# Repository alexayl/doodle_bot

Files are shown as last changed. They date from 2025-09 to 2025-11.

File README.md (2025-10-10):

# Doodle Bot

DoodleBot device for autonomous whiteboard management.

This repository is setup as a **monorepo** that contains the code for the different subsystems that are flashed to different devices. Please see the links below for each subsystems' README:

- [Firmware](firmware/README.md) (Alex Aylward and Jain Iftesam) is responsible for all of the code on the device.
- [CV Software](cv_software/README.md) (Trevor Antle is responsible for developing the Computer Vision application
- [Pathfinding](pathfinding/README.md) (Tom Concannon) is responsible for the path generation algorithm

## Setup

### Docs

Requirements: graphviz

### Firmware

_Note: If you are on a PC, Zephyr does not work well with WSL. Please use Windows native, or consider eventually dual-booting/VM linux!_

1. Install prerequisites

    - [Python3](https://www.geeksforgeeks.org/python/download-and-install-python-3-latest-version/)

    - Complete **only** the [Install Dependencies](https://docs.zephyrproject.org/latest/develop/getting_started/index.html#install-dependencies) section of the [Getting Started Guide](https://docs.zephyrproject.org/latest/develop/getting_started/index.html#getting-started-guide).

    - [Just command runner](https://github.com/casey/just?tab=readme-ov-file#installation) - This is used like a makefile as a hotkey for all of our project-specific commands
        - If you are using Windows, installing chocolatey package manager is recommended. After installing chocolatey, you can install just by running `choco install just`.
        - If you are on Mac, use the [Homebrew](https://brew.sh/) command `brew install just`.

If building/flsahing for [nrf52840 dk](https://docs.zephyrproject.org/latest/boards/nordic/nrf52840dk/doc/index.html):
    - SEGGER J-Link DLL
    - nrfutil (there is a python lib that allegedly has it; I needed to install it from the website though due to python dependency version conflicts)
    - 
2. Clone this repository:
    ```bash
    git clone git@github.com:alexayl/doodle_bot.git
    cd doodle_bot
    ```

3. Create and activate a Python virtual environment:
    ```bash
    python -m venv .venv
    
    source .venv/bin/activate     # Linux/macOS
    .venv\Scripts\activate.bat    # PC, Command Prompt
    .venv\Scripts\Activate.ps1    # PC, Powershell
    source .venv/Scripts/activate # PC. Git bash
    ```

4. Install west
    ```bash
    pip install west
    ```

5. Update the workspace
    ```bash
    cd firmware
    west update
    west packages pip --install
    ```

6. Install the Zephyr SDK
    1. navigate to `doodle_bot/firmware/zephyr`
        ```bash
        cd zephyr
        ```
    2.  Perform installation 
        ```bash
        west sdk install
        ```

7. Try to build and run
    1. navigate to `doodle_bot/firmware`
        ```bash
        cd ..
        ```
    2.  Build the sim to verify it works 
        ```bash
        just run-sim
        ```

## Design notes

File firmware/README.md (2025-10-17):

# Doodlebot Firmware
 
## Overview

The firmware contains two main parts. Please see the READMEs for each individual part for more information.

- [Application](app/README.md) (Alex Aylward) - The high-level logic
- [Drivers](drivers/README.md) (Jain Iftesam) - Hardware drivers and peripheral interfaces

## Features

- Bluetooth Low Energy (BLE) Nordic UART Service (NUS) support
- Real-time sensor data collection and processing
- Motor control and movement coordination
- Wireless communication with computer vision system
- Hardware abstraction layer for multiple board targets

## Installation

### Setup to work on firmware

Note: If you are on a Windows PC, use WSL2 (look up install instructions, ubuntu recommended) and follow the instructions for linux

1. Install prerequisites

    - Python3

    - Complete **only** the [Install Dependencies](https://docs.zephyrproject.org/latest/develop/getting_started/index.html#install-dependencies) section of the [Getting Started Guide](https://docs.zephyrproject.org/latest/develop/getting_started/index.html#getting-started-guide).

    - [Just command runner](https://github.com/casey/just?tab=readme-ov-file#installation) - This is used like a makefile as a hotkey for all of our project-specific commands
        - If you are using Windows, installing chocolatey package manager is recommended. After installing chocolatey, you can install just by running `choco install just`.
        - If you are on Mac, use the [Homebrew](https://brew.sh/) command `brew install just`.

    - **Windows + WSL2**: usbipd-win - This is used to expose the USB ports to WSL2 so that flashing works properly

2. Clone this repository:
    ```bash
    git clone git@github.com:alexayl/doodle_bot.git
    cd doodle_bot
    ```

3. Create and activate a Python virtual environment:
    ```bash
    python -m venv .venv
    
    source .venv/bin/activate     # Linux/macOS
    .venv\Scripts\activate.bat    # PC, Command Prompt
    .venv\Scripts\Activate.ps1    # PC, Powershell
    source .venv/Scripts/activate # PC. Git bash
    ```

4. Install west
    ```bash
    pip install west
    ```

5. Update the workspace
    ```bash
    cd firmware
    west update
    west packages pip --install
    ```

6. Install the Zephyr SDK
    1. navigate to `doodle_bot/firmware/zephyr`
        ```bash
        cd zephyr
        ```
    2. Perform installation 
        ```bash
        west sdk install
        ```

7. Try to build and run
    1. navigate to `doodle_bot/firmware`
        ```bash
        cd ..
        ```
    2. Build the sim to verify it works 
        ```bash
        just run-sim
        ```

## Usage

### Building and Flashing

For nRF52840 DK:
```bash
# Build for nrf52840dk
west build -b nrf52840dk/nrf52840 app

# Flash to board
west flash
```

For other targets, see individual application READMEs for board-specific instructions.

### Testing BLE Connectivity

1. Flash the peripheral_nus sample to your board
2. Use nRF Connect mobile app to scan and connect
3. Subscribe to NUS notifications to receive "Hello World!" messages
4. Send data to test bidirectional communication

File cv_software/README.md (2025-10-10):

# DoodleBot Computer Vision

## Overview
The Computer Vision (CV) subsystem provides real-time localization and feedback for the DoodleBot platform.  
It runs on a Raspberry Pi 5 and integrates camera-based perception, geometric calibration, and marker-based pose estimation using **OpenCV** and **ArUco** detection.  
The subsystem continuously tracks the robot’s position and orientation on the drawing board and communicates live correction data to the firmware over Bluetooth.  
A Flask-based web interface enables real-time monitoring through annotated video streams and provides REST APIs for control, status, and telemetry.

## Features
- **Multi-threaded Frame Capture:**  
  Captures frames asynchronously at up to 30 fps using a low-latency video backend with sharpness and exposure filtering.
- **Board Calibration and Homography Mapping:**  
  Uses four fixed ArUco markers to compute a perspective transform that aligns the camera’s image space to the board coordinate system.
- **Marker-Based Localization:**  
  Detects two robot-mounted fiducial markers to determine position and heading in millimeter-scale precision.
- **Dynamic Scaling:**  
  Automatically derives pixel-to-millimeter conversion from board geometry or marker baseline.
- **Web Visualization and Telemetry:**  
  Streams annotated video, calibration metrics, and robot pose data via Flask endpoints for live visualization and integration with other subsystems.

## Installation
1. Clone the repository:
   ```bash
   git clone https://github.com/alexayl/doodle_bot.git
   cd cv_software
   ```

2. Create a virtual environment and install dependencies:
   ```bash
   python3 -m venv venv
   source venv/bin/activate
   pip install -r requirements.txt
   ```

3. (Optional) To improve latency, enable MJPEG mode for UVC cameras on Linux:
   ```bash
   v4l2-ctl -d /dev/video0 --set-fmt-video=width=1280,height=720,pixelformat=MJPG
   ```

4. Launch the application:
   ```bash
   python3 -m app.server
   ```

## Usage
- Access the web interface at `http://<raspberrypi-ip>:5000`.
- Modes:
  - **/draw:** Upload an image for path rendering.
  - **/erase:** Command the robot to clear the workspace.
- API Endpoints:
  - `/api/moves` – enqueue motion commands.
  - `/api/pen` – toggle pen state (up/down).
  - `/api/stop` – halt motion.
  - `/stream` – retrieve the live annotated camera feed.
  - `/health` – report calibration and detection status.
- Logs and captured images are stored in the `uploads/` directory.

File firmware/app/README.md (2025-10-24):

# Doodlebot Firmware Application

## Overview

The main application firmware for the DoodleBot project. This firmware implements a multi-threaded architecture for controlling the robot's movement, communication, and state management. The application coordinates between Bluetooth communication, navigation control, and system state management through a message queue system.

## Architecture

The application uses a threaded architecture with three main threads:

- **Communications Thread** (`comms_thread`) - Handles Bluetooth Low Energy (BLE) communication via Nordic UART Service (NUS)
- **Navigation Thread** (`nav_thread`) - Processes movement instructions and controls servo motors
- **State Management Thread** (`state_thread`) - Manages overall system state and coordination

Communication between threads is handled through Zephyr message queues, specifically the `gcode_cmd_msgq` for navigation instructions.

## Features

- **Bluetooth Low Energy (BLE) Communication**
  - Nordic UART Service (NUS) implementation
  - Wireless command reception from computer vision system
  - Real-time data transmission

- **Multi-threaded Architecture** 
  - Concurrent processing of communication, navigation, and state management
  - Message queue-based inter-thread communication
  - Priority-based thread scheduling

- **Hardware Control**
  - PWM-based servo motor control
  - LED status indicators
  - Custom servo driver integration

- **Navigation System**
  - G-code instruction parsing and execution
  - Servo position control for drawing operations
  - Coordinated movement patterns

## Usage

### Building and Running

From the firmware directory, use the provided just commands:

```bash
# Build and run on nrf52840dk (complete workflow)
just run-nrf

# Individual steps:
just build-nrf     # Build the application
just flash-nrf     # Flash to board
just monitor-nrf   # Monitor serial output

# Build and run in QEMU simulator
just run-sim

# Build and run BLE sample
just run-ble
```

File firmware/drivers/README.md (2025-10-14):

# Doodlebot Firmware Drivers

## Overview

This directory contains custom Zephyr RTOS drivers for the Doodlebot drawing robot. The drivers provide a clean abstraction layer between high-level control algorithms and low-level hardware interfaces, enabling intuitive control of motors, actuators, and feedback devices.

## Architecture

The driver architecture follows a layered approach:

```
┌─────────────────────────────────────────┐
│          Application Layer              │
│     (Path Planning, Drawing Logic)      │
└─────────────────────────────────────────┘
                    │
┌─────────────────────────────────────────┐
│        Control Thread (50 Hz)          │
│    (Motor Control, State Management)    │
└─────────────────────────────────────────┘
                    │
┌─────────────────────────────────────────┐
│          Driver API Layer              │
│     (stepper.h, buzzer.h, servo.h)     │
└─────────────────────────────────────────┘
                    │
┌─────────────────────────────────────────┐
│        Hardware Abstraction            │
│     (GPIO, Timers, Device Tree)        │
└─────────────────────────────────────────┘
                    │
┌─────────────────────────────────────────┐
│          Physical Hardware             │
│  (A4988 Steppers, Servos, Buzzer)     │
└─────────────────────────────────────────┘
```

## Features

### Stepper Motor Driver
- **Input Interface**: Angular velocity in degrees/second
- **Hardware Support**: A4988/DRV8825 stepper driver modules
- **Microstepping**: 16x microstepping for smooth motion
- **Real-time Control**: Optimized for 50 Hz velocity updates
- **Dual Motor Support**: Independent left/right wheel control

### Servo Motor Driver  
- **Input Interface**: Angle in degrees (0-180°)
- **Hardware Support**: Standard PWM servo motors
- **Dual Servo Control**: Eraser and marker pen control
- **Smooth Movement**: PWM-based positioning

### LED Driver
- **Input Interface**: Simple on/off control
- **Hardware Support**: GPIO-controlled LEDs
- **Status Indication**: Visual feedback for system states
- **Multi-LED Support**: Independent control of multiple LEDs

### Buzzer Driver
- **Input Interface**: Simple on/off and beep patterns
- **Hardware Support**: GPIO-controlled piezo buzzer
- **Feedback**: Audio feedback for user interactions

## Driver Details

### Stepper Motor Driver (`stepper/`)

**Purpose**: Controls dual stepper motors for robot movement

**Key Specifications**:
- **Motor Type**: 1.8° stepper motors (200 steps/revolution)
- **Driver Modules**: A4988 or DRV8825 with 16x microstepping
- **Resolution**: 3200 microsteps per revolution
- **Conversion**: `f_step = velocity_deg_s × (3200/360) = velocity_deg_s × 8.89`

**API Functions**:
```c
int stepper_init(void);
int stepper_enable(enum stepper_motor motor);
int stepper_set_velocity(enum stepper_motor motor, float velocity_deg_s);
int stepper_stop(enum stepper_motor motor);
float stepper_get_velocity(enum stepper_motor motor);
```

**Device Tree Binding**: `dts/bindings/stepper/stepper-driver.yaml`
```yaml
stepper_left: stepper_left {
    compatible = "doodle,a4988-stepper";
    micro-step-res = <16>;
    step-gpios = <&gpio0 5 GPIO_ACTIVE_HIGH>;      /* ESP32: GPIO5, nRF52: P0.02 */
    dir-gpios = <&gpio0 6 GPIO_ACTIVE_HIGH>;       /* ESP32: GPIO6, nRF52: P0.03 */
    en-gpios = <&gpio0 7 GPIO_ACTIVE_LOW>;         /* ESP32: GPIO7, nRF52: P0.04 */
    label = "LEFT_STEPPER";
};
```

**Hardware Interface**:
- **STEP**: GPIO pulse train at calculated frequency
- **DIR**: GPIO level for rotation direction (HIGH = clockwise)
- **EN**: GPIO level for driver enable/disable (Active LOW)

**A4988/DRV8825 Driver Connections**:
```
ESP32-S3/nRF52840 → A4988/DRV8825 Driver
STEP pin          → STEP
DIR pin           → DIR
EN pin            → EN (Enable)
3.3V              → VDD (logic power)
3.3V              → RESET (tie high)
3.3V              → SLEEP (tie high)
3.3V              → MS1, MS2, MS3 (for 16x microstepping)
GND               → GND
                    VMOT ← 12V Motor Power Supply
                    1A, 1B, 2A, 2B → Stepper Motor Phases
```

**Real-time Operation**:
- Designed for 50 Hz velocity updates from control thread
- Uses Zephyr timers for precise step pulse generation
- Optimizes GPIO writes by only changing direction when needed

**Pseudocode Implementation**:

```pseudocode
// ========== CORE CONCEPT ==========
// We convert degrees/second to timer interrupts that toggle GPIO pins
// 1.8° motor + 16x microstepping = 3200 steps per full rotation
// So: 1 deg/s = 8.89 steps/s

// ========== MAIN VELOCITY FUNCTION ==========
FUNCTION stepper_set_velocity(motor, velocity_deg_s):
    // Step 1: Convert degrees/s to step frequency
    steps_per_second = abs(velocity_deg_s) * 8.89
    
    // Step 2: Determine direction (positive = clockwise)
    clockwise = (velocity_deg_s >= 0)
    
    // Step 3: Set direction pin (only if direction changed)
    IF direction_changed:
        gpio_set(direction_pin, clockwise)
    
    // Step 4: Start timer to generate step pulses
    IF steps_per_second > 0 AND motor_enabled:
        timer_period = 500000 / steps_per_second  // microseconds
        start_timer(timer_period)
    ELSE:
        stop_timer()

// ========== TIMER INTERRUPT ==========
TIMER_INTERRUPT step_pulse_generator():
    // This runs every timer_period microseconds
    toggle_gpio(step_pin)  // Creates the step pulse for A4988

// ========== MOTOR CONTROL ==========
FUNCTION stepper_enable(motor):
    gpio_set(enable_pin, LOW)    // A4988 enable is active LOW
    motor_enabled = TRUE

FUNCTION stepper_disable(motor):
    stop_timer()                 // Stop stepping first
    gpio_set(enable_pin, HIGH)   // Disable A4988
    motor_enabled = FALSE

// ========== SIMPLE EXAMPLE ==========
// stepper_set_velocity(LEFT_MOTOR, 180.0)
// 
// 1. steps_per_second = 180 * 8.89 = 1600 Hz
// 2. timer_period = 500000 / 1600 = 312.5 μs
// 3. Timer toggles GPIO every 312.5 μs
// 4. Result: 1600 step pulses per second = 0.5 revolutions/s = 180°/s
```

### Example Calculations

| Input Velocity | Step Frequency | Timer Period | Physical Result |
|---|---|---|---|
| 360 deg/s | 3200 steps/s | 156.25 μs | 1.0 rev/s |
| 180 deg/s | 1600 steps/s | 312.5 μs | 0.5 rev/s |
| 90 deg/s | 800 steps/s | 625 μs | 0.25 rev/s |

### Servo Motor Driver (`servo/servo.c`)

**Purpose**: Controls servo motors for drawing tool positioning

**Hardware Support**: Standard PWM servo motors (SG90, MG996R, etc.)

**API Functions**:
```c
int servo_init(void);
int servo_set_angle(enum servo_motor servo, float angle_degrees);
float servo_get_angle(enum servo_motor servo);
```

**Pseudocode Implementation**:
```pseudocode
FUNCTION servo_set_angle(servo, angle_degrees):
    // Convert angle to PWM duty cycle
    // Standard servo: 1ms (0°) to 2ms (180°) pulse width
    pulse_width_us = 1000 + (angle_degrees / 180.0) * 1000
    duty_cycle = pulse_width_us / 20000  // 20ms period
    
    // Update PWM channel
    pwm_set_duty_cycle(servo_pwm_channel, duty_cycle)
    
    // Store current angle
    servo_state[servo].current_angle = angle_degrees
```

### LED Driver (`led/led_gpio.c`)

**Purpose**: Provides visual status indication and user feedback

**Hardware Support**: GPIO-controlled LEDs (power, status, drawing indicators)

**API Functions**:
```c
int led_init(void);
int led_on(enum led_type led);
int led_off(enum led_type led);
int led_toggle(enum led_type led);
int led_blink(enum led_type led, uint32_t period_ms);
```

**Device Tree Binding**: `gpio-leds.yaml`
```yaml
leds {
    compatible = "gpio-leds";
    led_power: led-power {
        gpios = <&gpio0 15 GPIO_ACTIVE_HIGH>;
        label = "Power LED";
    };
    led_drawing: led-drawing {
        gpios = <&gpio0 16 GPIO_ACTIVE_HIGH>;
        label = "Drawing Status LED";
    };
};
```

**Pseudocode Implementation**:
```pseudocode
FUNCTION led_on(led_type):
    gpio_set(led_gpio[led_type], HIGH)
    led_state[led_type] = ON

FUNCTION led_blink(led_type, period_ms):
    led_state[led_type] = BLINKING
    start_timer(period_ms/2, led_blink_callback)

TIMER_INTERRUPT led_blink_callback():
    toggle_gpio(led_gpio[led_type])
```

### Buzzer Driver (`buzzer/`)

**Purpose**: Provides audio feedback for user interactions

**Hardware Support**: GPIO-controlled piezo buzzer

**API Functions**:
```c
int buzzer_init(void);
int buzzer_on(void);
int buzzer_off(void);
int buzzer_beep(uint32_t duration_ms);
```

**Pseudocode Implementation**:
```pseudocode
FUNCTION buzzer_beep(duration_ms):
    gpio_set(buzzer_gpio, HIGH)
    start_timer(duration_ms, buzzer_off_callback)

TIMER_INTERRUPT buzzer_off_callback():
    gpio_set(buzzer_gpio, LOW)

FUNCTION buzzer_on():
    gpio_set(buzzer_gpio, HIGH)
    buzzer_state = ON

FUNCTION buzzer_off():
    gpio_set(buzzer_gpio, LOW)
    buzzer_state = OFF
```

## Testing

Each driver includes comprehensive tests in the `../tests/` directory (relative to drivers/):

### Stepper Motor Tests (`../tests/stepper/stepper_control.cpp`)
**Purpose**: Validates stepper motor velocity control and direction changes
**Test Pattern**:
```cpp
// Continuous test cycle:
1. Forward rotation: 360°/s (1 revolution/second) for 2 seconds
2. Stop for 1 second  
3. Reverse rotation: -180°/s (0.5 revolution/second) for 2 seconds
4. Stop for 2 seconds and repeat
```
**Expected Behavior**: Left stepper motor should make 2 full forward rotations, pause, then 1 reverse rotation, creating a distinctive back-and-forth pattern
**Hardware Validation**: Visually confirm motor rotation direction and speed match the programmed values

### Servo Motor Tests (`../tests/servo/servo_control.cpp`)
**Purpose**: Tests dual servo positioning for eraser and marker control
**Test Pattern**:
```cpp
// Synchronized servo movement with offset pattern:
Eraser positions: 0° → 90° → 180° → 90° → repeat
Marker positions: 180° → 90° → 0° → 90° → repeat (offset by 2 steps)
```
**Expected Output**:
```
Dual Servo Demo - Eraser: servo_eraser, Marker: servo_marker
Eraser: 0°, Marker: 180°
Eraser: 90°, Marker: 90° 
Eraser: 180°, Marker: 0°
Eraser: 90°, Marker: 90°
```
**Hardware Validation**: Both servo horns should move in coordinated but offset patterns

### LED Driver Tests (`../tests/led/led_control.cpp`)
**Purpose**: Tests LED abstraction layer and GPIO control
**Test Pattern**:
```cpp
// Simple ON/OFF toggle with driver abstraction:
500ms ON → 500ms OFF → repeat
Uses led_command_t enum (LED_ON/LED_OFF) sent to led_driver_set()
```
**Expected Output**:
```
LED Driver Test starting...
LED device initialized successfully
GPIO11 LED driver ready
Testing both ACTIVE_HIGH and ACTIVE_LOW configurations...
LED ON
LED ON
LED ON
...
```
**Hardware Validation**: Status LED should blink at 1Hz (500ms on, 500ms off)

### Buzzer Driver Tests (`../tests/buzzer/buzzer_test.cpp`)
**Purpose**: Tests buzzer GPIO control and audio feedback
**Test Pattern**:
```cpp
// Simple buzzer toggle:
500ms ON → 500ms OFF → repeat
Uses buzzer_toggle() function for state changes
```
**Expected Output**:
```
Buzzer Driver Test - 20ms Toggle
Buzzer initialized successfully - starting toggle test
```
**Hardware Validation**: Should hear intermittent buzzer sound at 1Hz

**Run tests with justfile commands**:
```bash
# Stepper motor tests
just test-nrf-stepper    # nRF52840DK: Pins P0.02, P0.03, P0.04
just test-esp-stepper    # ESP32-S3: Pins GPIO5, GPIO6, GPIO7

# Servo motor tests  
just test-nrf-servo      # nRF52840DK: PWM pins P0.13, P0.03
just test-esp-servo      # ESP32-S3: PWM pins GPIO2, GPIO3

# LED tests
just test-nrf-led        # nRF52840DK: GPIO P0.14
just test-esp-led        # ESP32-S3: GPIO11

# Buzzer tests
just test-nrf-buzzer     # nRF52840DK: GPIO P0.15
just test-esp-buzzer     # ESP32-S3: GPIO12
```

**Test Build System Integration**:
Tests are integrated into the CMake build system via `CONFIG_*_TEST` flags:
- `CONFIG_STEPPER_TEST=y` → Builds `stepper_control.cpp` + `stepper.c`
- `CONFIG_SERVO_TEST=y` → Builds `servo_control.cpp` + `servo.c`
- `CONFIG_LED_TEST=y` → Builds `led_control.cpp` + `led_gpio.c`
- `CONFIG_BUZZER_TEST=y` → Builds `buzzer_test.cpp` + `buzzer.c`

## Hardware Configuration

### Platform Support
- **Primary**: ESP32-S3 DevKitC
- **Secondary**: Nordic nRF52840 DK

### Pin Assignments
See device tree overlay files for complete pin mappings:
- `app/boards/esp32s3_devkitc_procpu.overlay` (ESP32-S3 DevKitC)
- `app/boards/nrf52840dk_nrf52840.overlay` (Nordic nRF52840 DK)

**ESP32-S3 DevKitC Pinout**:
```
Left Stepper:  GPIO5 (STEP), GPIO6 (DIR), GPIO7 (EN)
Right Stepper: GPIO8 (STEP), GPIO9 (DIR), GPIO10 (EN) [disabled]
Servo Eraser:  GPIO2 (PWM)
Servo Marker:  GPIO3 (PWM)
Status LED:    GPIO11
Buzzer:        GPIO12
```

**nRF52840 DK Pinout**:
```
Left Stepper:  P0.02 (STEP), P0.03 (DIR), P0.04 (EN)
Right Stepper: P0.05 (STEP), P0.06 (DIR), P0.07 (EN)
Servo Eraser:  P0.13 (PWM)
Servo Marker:  P0.03 (PWM) [shared with stepper DIR]
Status LED:    P0.14
Buzzer:        P0.15
```

## Development Notes

### Performance Considerations
- Stepper driver optimized for high-frequency operation (>3 kHz step rates)
- Direction changes minimized to reduce GPIO overhead
- Timer-based pulse generation for precise timing

### Error Handling
- Graceful degradation on hardware initialization failures
- Parameter validation for velocity and angle limits
- Logging integration for debugging and monitoring

### Future Enhancements
- **Stepper Improvements**: Acceleration/deceleration profiles for smoother motion
- **Position Feedback**: Closed-loop position control with encoders
- **Dynamic Microstepping**: Adaptive microstepping based on speed requirements
- **Power Management**: Sleep modes and current reduction during idle
- **Dual Motor Coordination**: Synchronized control for differential drive
- **Safety Features**: Thermal protection and stall detection
- **Integration**: Integrate with Core Firmware

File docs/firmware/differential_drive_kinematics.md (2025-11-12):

# Differential Drive Kinematics

## Goal

Convert G-code G1 commands, which specify relative changes in tool head position in the $X$ and $Y$ directions (mm), into wheel angular velocities for a differential drive robot.

## Method

This method uses linear interpolation between points. This may be extended to cubic hermite interpolation in the future.

## Derivation

$$
(\Delta x, \Delta y) \;\rightarrow\; (d, \Delta \theta) \;\rightarrow\; (v_l, v_r) \;\rightarrow\; (\omega_l, \omega_r)
$$

### 1. Cartesian Δ to Polar Δ

Each change in position can be decomposed into two movements:
1. A change in heading angle, $\Delta \theta$
2. A change in path length, $d$

$$
d = \sqrt{(\Delta x)^2 + (\Delta y)^2} \\
\theta' = \operatorname{atan2}(\Delta y, \Delta x) \\
\Delta \theta = \theta' - \theta
$$

### 2. Polar Δ to Differential Wheel Displacements

Let $r_{\text{doodlebot}}$ represent half the wheelbase, i.e., the distance from the robot’s center to each wheel.  

Then the displacement of each wheel is:

$$
d_l = d - \Delta \theta \, r_{\text{doodlebot}} \\
d_r = d + \Delta \theta \, r_{\text{doodlebot}}
$$

### 3. Wheel Displacements to Linear Velocities

The stepper control period $T$ determines how long the motion should take. Let the control frequency be $f = \frac{1}{T}$.

$$
v_l = d_l \, f \\
v_r = d_r \, f
$$

This is where rate limiting must occurr. The physical speed limit of the DoodleBot is surely lower than the stepper motor or driver’s angular limit, as specified by the datasheet. If either $v_l$ or $v_r$ exceeds the maximum allowable linear velocity, they are broken into multiple movements of mangeable velocity to achieve the commanded distance. Subsequent transformations are applied for each new movement.

### 4. Linear to Angular Velocity

The standard kinematic relationship is:

$$
v = r_{\text{wheel}} \, \omega
$$

Rearranging for $\omega$ gives:

$$
\omega = \frac{v}{r_{\text{wheel}}}
$$

Thus, for each wheel:

$$
\omega_l = \frac{v_l}{r_{\text{wheel}}}, \quad
\omega_r = \frac{v_r}{r_{\text{wheel}}}
$$

### 5. Radians to Degrees (Stepper Driver Input)

Most stepper drivers accept angular velocities in degrees per second, so convert as:

$$
\omega_{l,°} = \omega_l \cdot \frac{180}{\pi}, \quad
\omega_{r,°} = \omega_r \cdot \frac{180}{\pi}
$$

## Implementation

The kinematics are implemented in `navigation.cpp` in the `MotionPlanner` class.

Step 1 happens in `interpolate()` which converts G-code coordinates to distance and angle commands. This is separated in the case of another interpolation method besides linear being used, this will be the only function that needs to change.

Steps 2-5 happen in `discretize()` which converts those commands to stepper motor velocities.

Physical constants like wheel radius and robot dimensions are defined in `navigation.h`.

Rate limiting occurs at Step 3 by splitting high velocities into multiple smaller movements.

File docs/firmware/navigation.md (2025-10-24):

Gcode -> interpolate (queue of nav commands) -> discretization (turn nav into velocities)

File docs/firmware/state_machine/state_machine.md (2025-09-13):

# Developing the state machine

To do still
- [ ] Talk with team to define full state machine, and program all states
- [ ] Write testing framework to validate chosen states
- [ ] Write state thread code to integrate with state machine

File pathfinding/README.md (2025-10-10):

# Doodlebot Pathfinding
 
## Overview

image2graph

The Pathfinding Algorithm subsystem serves as the core logic of the DoodleBot’s drawing operation, transforming an input image into a sequence of executable motion commands in the form of G-code. Implemented entirely in Python, the algorithm follows a structured multi-stage pipeline designed to extract drawable paths, determine an efficient traversal order, and generate precise motion instructions for the robot.

The process begins when the CV application subsystem supplies an image source and canvas parameters. The algorithm first applies Canny edge detection to the image to isolate prominent boundaries, producing an edge map that captures the essential drawing strokes. From this edge map, a graph is constructed by converting edge pixels into nodes and connecting neighboring pixels. The graph is then optimized through pruning operations that remove redundant nodes and edges, enforce disjoint line segments, and simplify straight paths via collinearity pruning. Smaller, negligible components are discarded to reduce computational load and maintain fidelity to the original image.

Once the image is reduced to a set of line segments, the Graph-to-Path Algorithm determines an efficient traversal order by formulating the problem as a Traveling Salesman Problem (TSP). Using the nearest neighbor heuristic to generate an initial path, and refining it with the 2-opt algorithm to remove crossings and minimize path length, the subsystem produces a compact and efficient tour that visits all segments exactly once.

Finally, the optimized path is converted into G-code using relative positioning commands. For each pair of consecutive points, positional deltas (dx, dy) are computed, and corresponding G1 X{dx} Y{dy} commands are generated under incremental mode (G91). Marker control is handled through the Z axis, lifting the marker between disconnected segments to prevent unintended strokes. The resulting G-code is saved for execution by the CV subsystem, enabling DoodleBot to accurately reproduce the input image.

In erasing mode, the pathfinding process is simplified. Instead of analyzing an image, the algorithm generates a full-coverage zig-zag pattern across the canvas, ensuring complete erasure. This path is similarly converted into G-code for robot execution.

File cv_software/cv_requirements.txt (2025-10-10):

blinker==1.9.0
cairocffi==1.7.1
CairoSVG==2.8.2
certifi==2025.8.3
cffi==2.0.0
charset-normalizer==3.4.3
click==8.3.0
cssselect2==0.8.0
defusedxml==0.7.1
Flask==3.1.2
future==1.0.0
idna==3.10
iniconfig==2.1.0
iso8601==2.1.0
itsdangerous==2.2.0
Jinja2==3.1.6
MarkupSafe==3.0.3
numpy==2.2.6
opencv-contrib-python==4.9.0.80
opencv-contrib-python-headless==4.12.0.88
opencv-python==4.9.0.80
opencv-python-headless==4.12.0.88
packaging==25.0
pillow==11.3.0
pluggy==1.6.0
pycparser==2.23
Pygments==2.19.2
PyQt5==5.15.11
PyQt5-Qt5==5.15.17
PyQt5_sip==12.17.0
PySide6==6.9.2
PySide6_Addons==6.9.2
PySide6_Essentials==6.9.2
pytest==8.4.2
PyYAML==6.0.3
reportlab==4.4.4
requests==2.32.5
serial==0.0.97
setuptools==80.9.0
shiboken6==6.9.2
tinycss2==1.4.0
urllib3==2.5.0
webencodings==0.5.1
Werkzeug==3.1.3
wheel==0.45.1

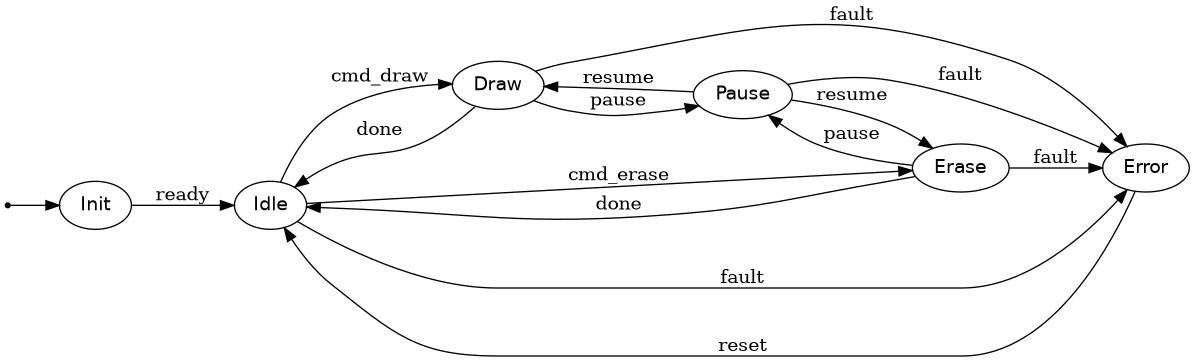
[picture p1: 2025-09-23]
docs/firmware/state_machine/state_machine.png

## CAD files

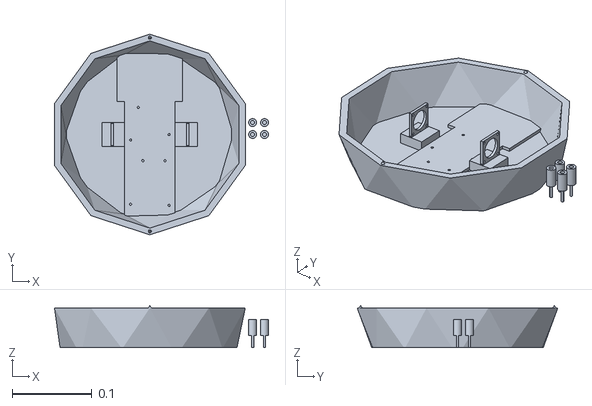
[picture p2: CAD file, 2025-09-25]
model/doodle_bot.stl
0.269 x 0.252 x 0.0529

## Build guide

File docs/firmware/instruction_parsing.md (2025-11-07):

# How the firmware parses movements

## Why G-Code?

Industry-standard for CNC machines, 3D printers, etc with well-defined and battle-tested set of commands for traversing 3d space.

## Subset of G-Code supported in MVP

- G91 - relative positioning (moves specified to bot's current position)
    - `G91`
- G1 - Linear-interpolated movement
    - `G1 X<mm> Y<mm>`
- M280 - Moves servos eraser and marker
    - `M280 P<pin_or_servo_index> S<position>` with `0` for pen servo and `1` for the eraser servo as pins, and the position [0, 180]

## How is G-Code transmitted?

G-code is transmitted via BLE using the Nordic UART Service (NUS) this exposes and RX and TX characteristic allowing for packets to be send both ways. The host will send each G-code line one at a time in plain text, and the firmware will send an acknowledgement back for each successful command that has been issued to the appropriate peripheral.

The first byte of each packet is the packet id. This value is an 8 bit integer (0-255) that increments with each packet sent.

## Example G-Code packets being sent

```
<pid>M280 P1 S90    // set eraser up
<pid>G91            // turn on relative positioning
<pid>M280 P0 S0     // set the pen down
<pid>G1 X10 Y-10    // move to the right 10 mm and down 10 mm
```

## Packet acknowledgement

After each packet is received by the firmware, it is parsed and queued for operation. Once the operation begins on the appropriate peripheral (e.g. step commands are sent for G1), these are the commands sent:

```
<pid>ok             // packet successfully parsed
<pid>fail           // packet unsuccessfully parsed     
```

## Protecting against corrupted packets

If the G-code parser fails to parse a command (it received a packet with the incorrect packet id, or the command was invalid) it will ask for a retry by sending the fail command.

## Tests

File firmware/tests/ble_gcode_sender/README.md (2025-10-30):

# BLE G-Code Sender

A Python-based tool for sending G-code files to the Doodle Bot over Bluetooth Low Energy (BLE) using the Nordic UART Service (NUS).

See main.py for an example of how to use BLEPacketHandler.

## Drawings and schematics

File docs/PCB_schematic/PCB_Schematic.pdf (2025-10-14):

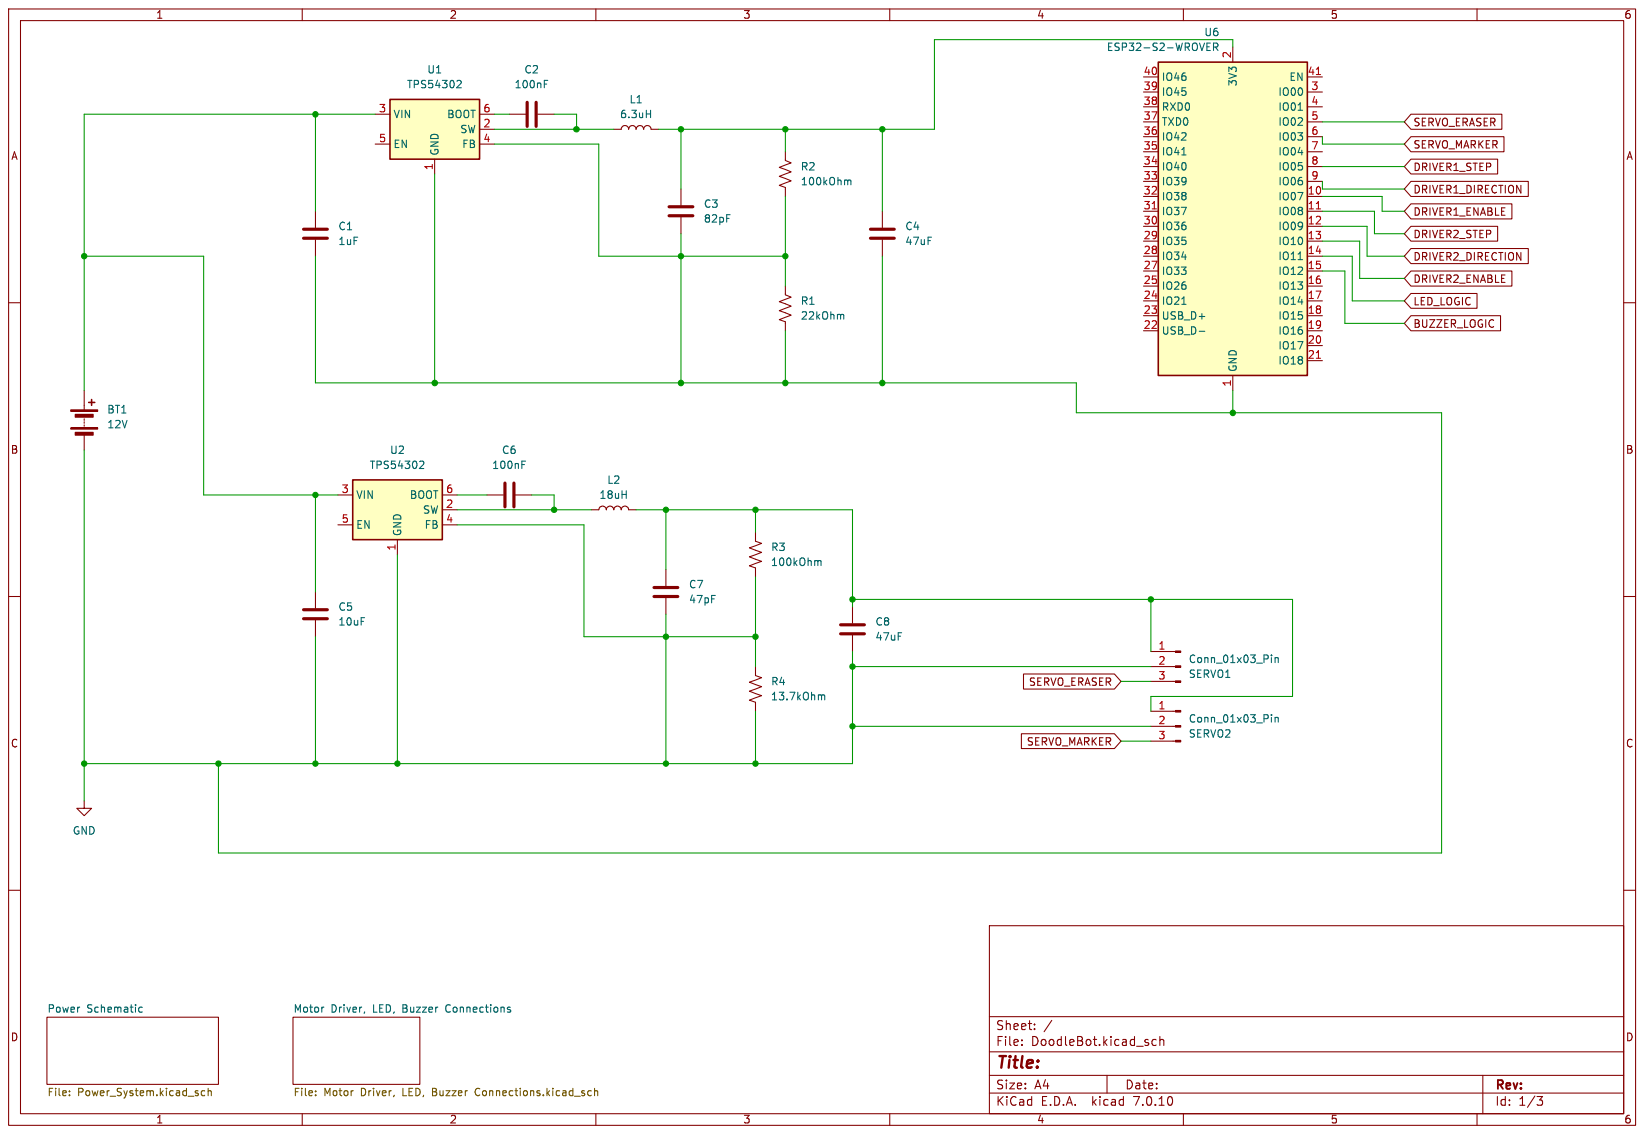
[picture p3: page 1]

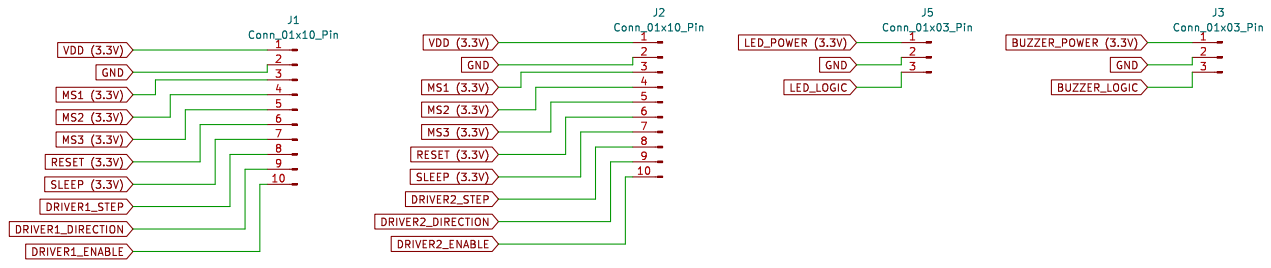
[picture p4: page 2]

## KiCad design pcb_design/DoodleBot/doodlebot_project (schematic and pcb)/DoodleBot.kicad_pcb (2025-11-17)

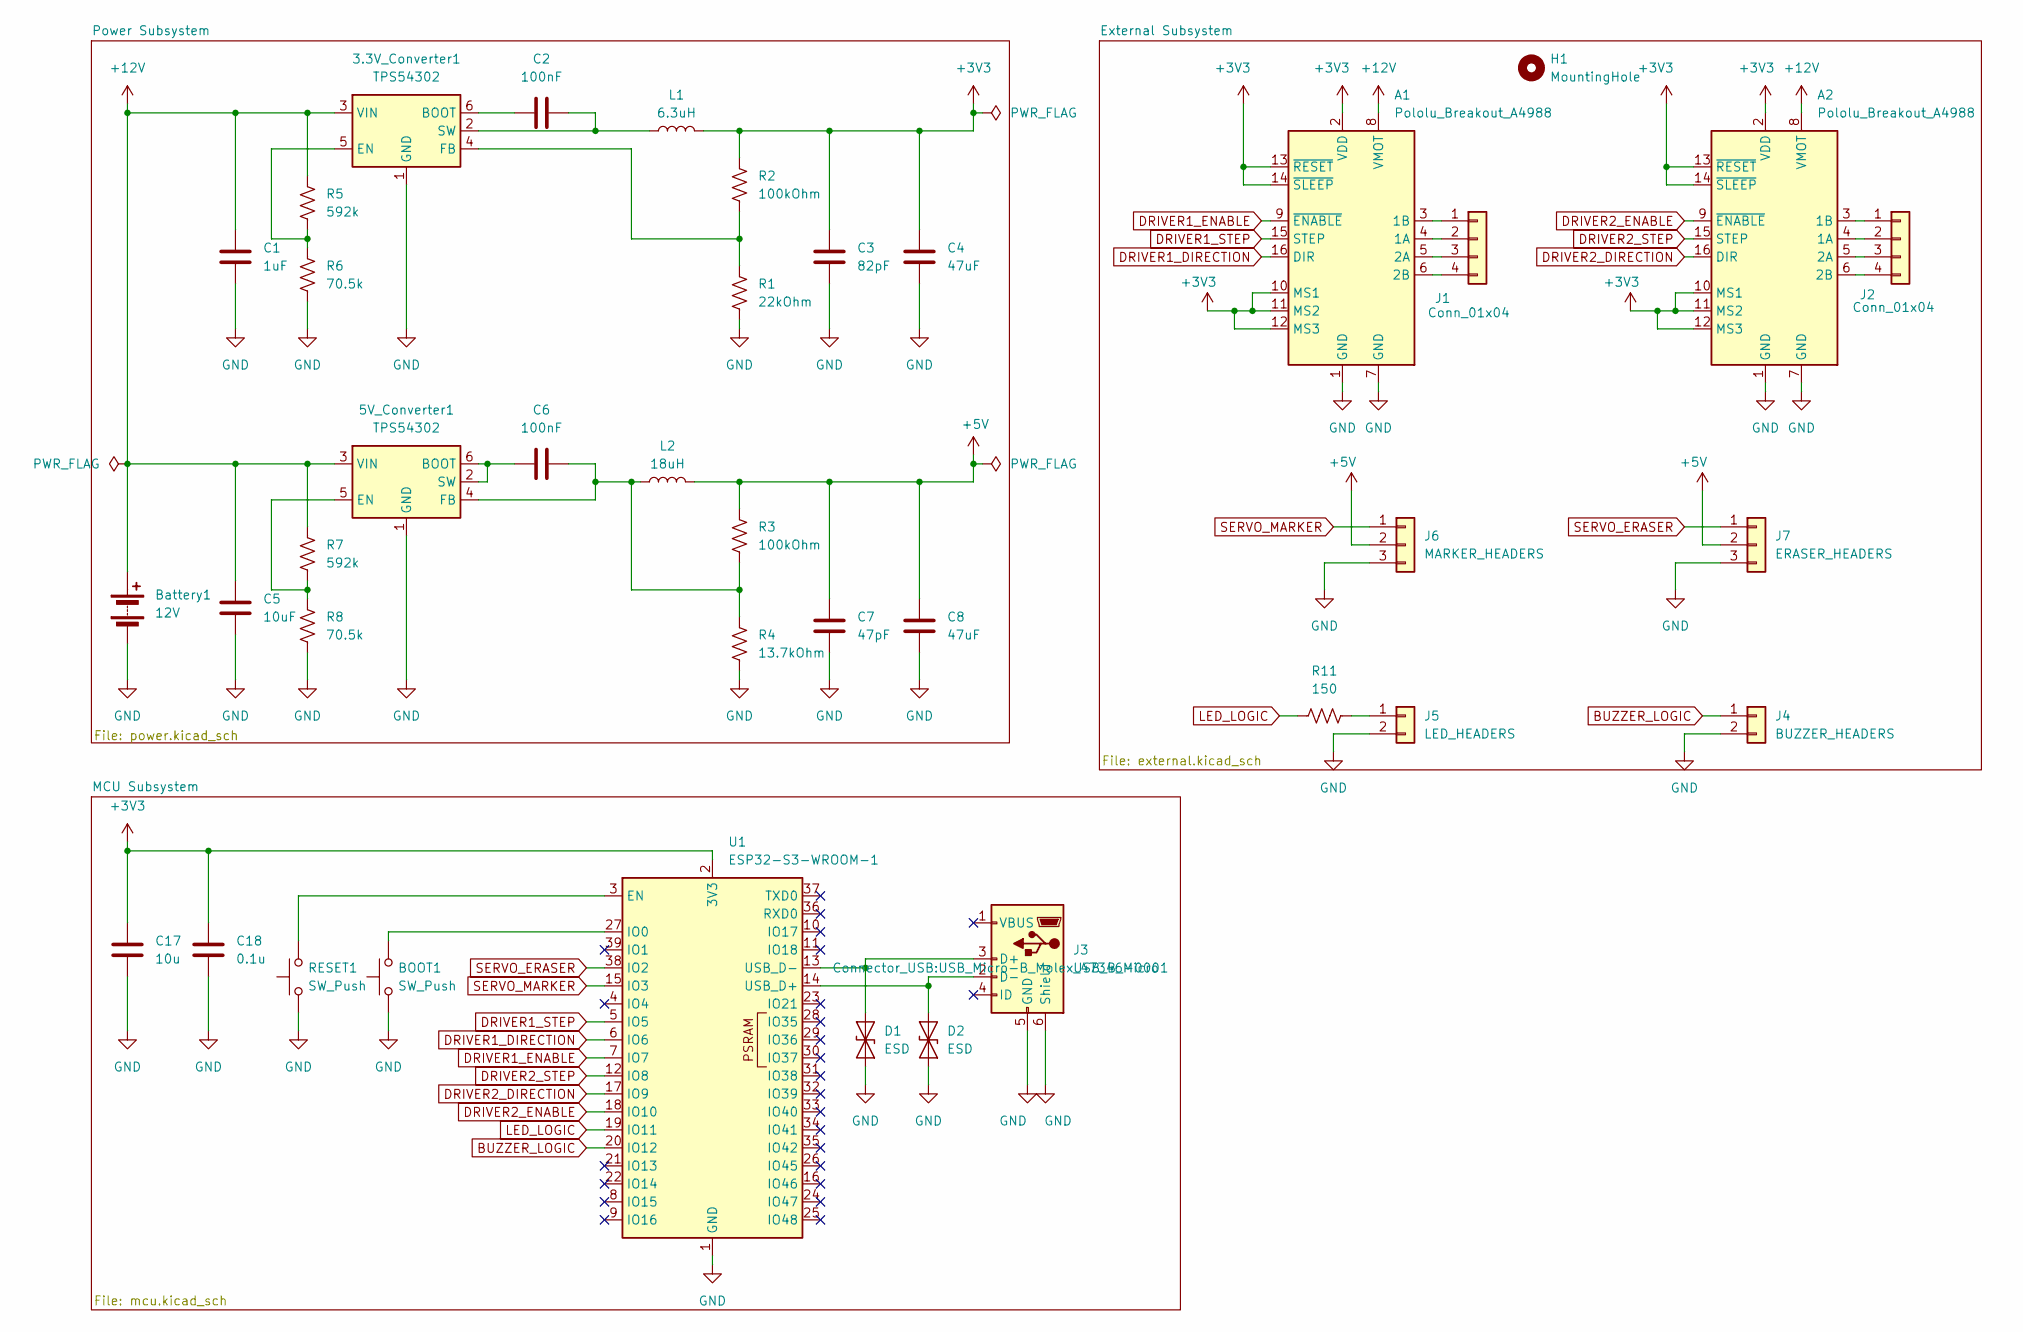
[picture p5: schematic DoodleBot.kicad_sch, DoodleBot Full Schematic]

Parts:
3.3V_Converter1, 5V_Converter1: TPS54302; SOT-23-6
A1, A2: Pololu_Breakout_A4988; Pololu_Breakout-16_15.2x20.3mm
BOOT1: SW_Push; SW_SPST_PTS647_Sx38
Battery1: 12V; PinHeader_1x02_P2.54mm_Vertical
C1: 1uF; C_0603_1608Metric
C2, C6: 100nF; C_0603_1608Metric
C3: 82pF; C_0603_1608Metric
C4, C8: 47uF; C_0603_1608Metric
C5: 10uF; C_0603_1608Metric
C7: 47pF; C_0603_1608Metric
C17: 10u; C_0603_1608Metric
C18: 0.1u; C_0603_1608Metric
D1, D2: ESD; D_0603_1608Metric
H1: MountingHole; MountingHole_2mm
J1, J2: Conn_01x04; PinHeader_1x04_P2.54mm_Vertical
J3: USB_B_Micro; USB_Micro-B_Molex_47346-0001
J4: BUZZER_HEADERS; PinHeader_1x02_P2.54mm_Vertical
J5: LED_HEADERS; PinHeader_1x02_P2.54mm_Vertical
J6: MARKER_HEADERS; PinHeader_1x03_P2.54mm_Vertical
J7: ERASER_HEADERS; PinHeader_1x03_P2.54mm_Vertical
L1: 6.3uH; L_Radial_D6.0mm_P4.00mm
L2: 18uH; L_Radial_D6.0mm_P4.00mm
R1: 22kOhm; R_0603_1608Metric
R2, R3: 100kOhm; R_0603_1608Metric
R4: 13.7kOhm; R_0603_1608Metric
R5, R7: 592k; R_0603_1608Metric
R6, R8: 70.5k; R_0603_1608Metric
R11: 150; R_0603_1608Metric
RESET1: SW_Push; SW_SPST_PTS647_Sx38
U1: ESP32-S3-WROOM-1

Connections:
+3V3: A1.2 (VDD), A1.10 (MS1), A1.11 (MS2), A1.12 (MS3), A1.13 (~RESET), A1.14 (~SLEEP), A2.2 (VDD), A2.10 (MS1), A2.11 (MS2), A2.12 (MS3), A2.13 (~RESET), A2.14 (~SLEEP), C3.2, C4.2, C17.1, C18.1, L1.2, R2.1, U1.2 (3V3)
+5V: C7.2, C8.2, J6.2, J7.2, L2.2, R3.1
+12V: 3.3V_Converter1.3 (VIN), 5V_Converter1.3 (VIN), A1.8 (VMOT), A2.8 (VMOT), Battery1.1 (+), C1.1, C5.1, R5.1, R7.1
BUZZER_LOGIC: J4.1, U1.20 (IO12)
DRIVER1_DIRECTION: A1.16 (DIR), U1.6 (IO6)
DRIVER1_ENABLE: A1.9 (~ENABLE), U1.7 (IO7)
DRIVER1_STEP: A1.15 (STEP), U1.5 (IO5)
DRIVER2_DIRECTION: A2.16 (DIR), U1.17 (IO9)
DRIVER2_ENABLE: A2.9 (~ENABLE), U1.18 (IO10)
DRIVER2_STEP: A2.15 (STEP), U1.12 (IO8)
GND: 3.3V_Converter1.1 (GND), 5V_Converter1.1 (GND), A1.1 (GND), A1.7 (GND), A2.1 (GND), A2.7 (GND), BOOT1.1, Battery1.2 (-), C1.2, C3.1, C4.1, C5.2, C7.1, C8.1, C17.2, C18.2, D1.1 (A1), D2.1 (A1), J3.5 (GND), J3.6 (Shield), J4.2, J5.2, J6.3, J7.3, R1.2, R4.2, R6.2, R8.2, RESET1.1, U1.1 (GND), U1.40 (GND), U1.41 (GND)
LED_LOGIC: R11.1, U1.19 (IO11)
unnamed: 3.3V_Converter1.6 (BOOT), C2.1
unnamed: 3.3V_Converter1.5 (EN), R5.2, R6.1
unnamed: 3.3V_Converter1.4 (FB), R1.1, R2.2
unnamed: 3.3V_Converter1.2 (SW), C2.2, L1.1
unnamed: 5V_Converter1.2 (SW), 5V_Converter1.6 (BOOT), C6.1
unnamed: 5V_Converter1.5 (EN), R7.2, R8.1
unnamed: 5V_Converter1.4 (FB), C6.2, L2.1, R3.2, R4.1
unnamed: A1.4 (1A), J1.2
unnamed: A1.3 (1B), J1.1
unnamed: A1.5 (2A), J1.3
unnamed: A1.6 (2B), J1.4
unnamed: A2.4 (1A), J2.2
unnamed: A2.3 (1B), J2.1
unnamed: A2.5 (2A), J2.3
unnamed: A2.6 (2B), J2.4
unnamed: D1.2 (A2), J3.3 (D+), U1.13 (USB_D-)
unnamed: D2.2 (A2), J3.2 (D-), U1.14 (USB_D+)
unnamed: J5.1, R11.2
unnamed: RESET1.2, U1.3 (EN)
unnamed: BOOT1.2, U1.27 (IO0)
SERVO_ERASER: J7.1, U1.38 (IO2)
SERVO_MARKER: J6.1, U1.15 (IO3)

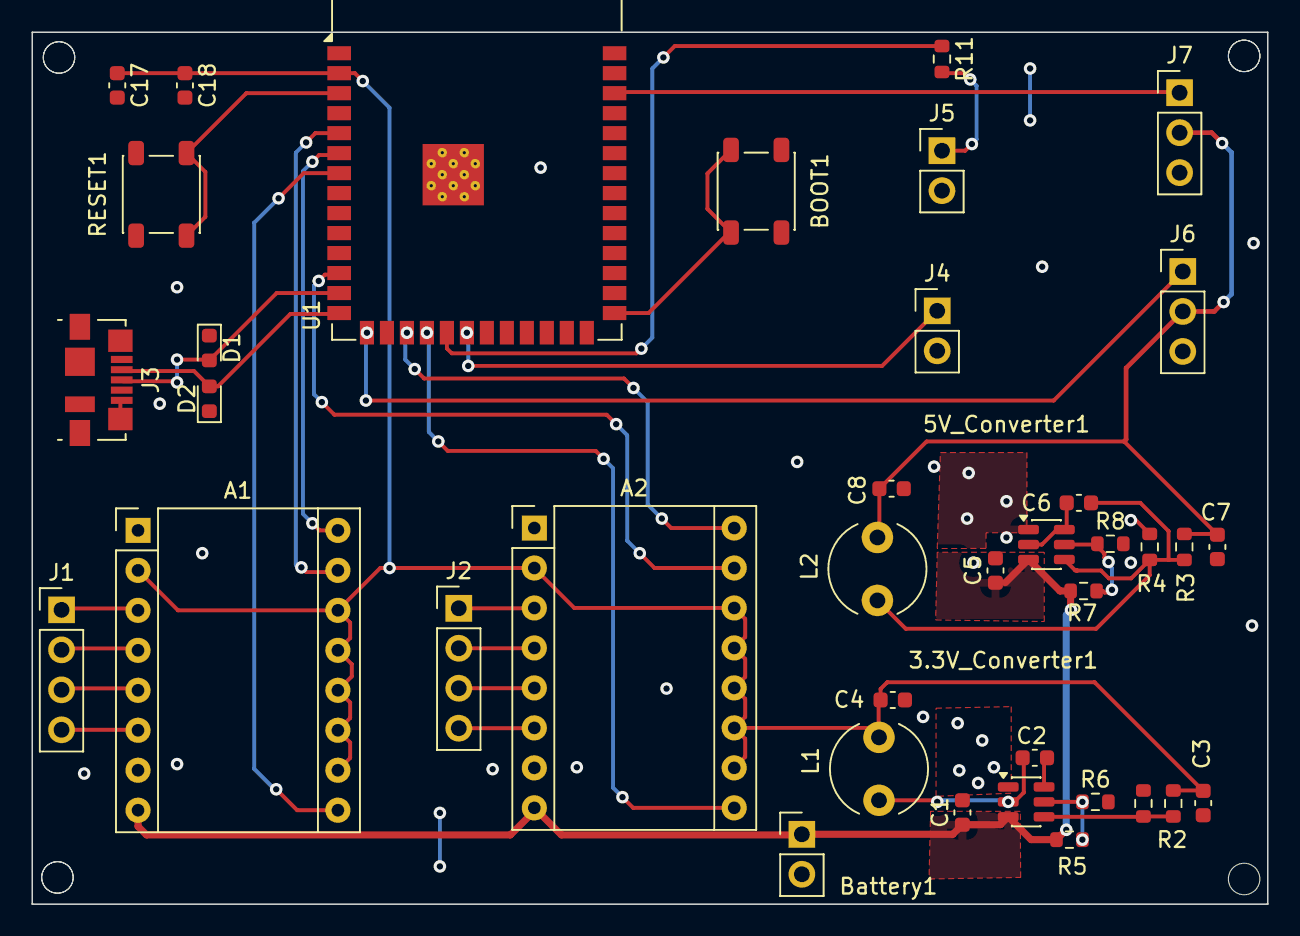
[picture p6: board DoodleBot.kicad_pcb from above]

Board: 2 copper layers, 78.5 x 55.4 mm, 38 parts (0 on the bottom side), 34 nets.

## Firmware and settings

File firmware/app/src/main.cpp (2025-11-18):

#include <zephyr/kernel.h>
#include <stdlib.h>
#include <zephyr/sys/printk.h>

#include "instruction_parser.h"
#include "comms_thread.h"
#include "navigation.h"
#include "state_task.h"
#include "stepper.h"


/* QUEUE MANAGEMENT */

#define MESSAGES_PER_QUEUE 200

K_MSGQ_DEFINE(gcode_cmd_msgq, sizeof(InstructionParser::GCodeCmd), MESSAGES_PER_QUEUE, alignof(InstructionParser::GCodeCmd));
K_MSGQ_DEFINE(nav_cmd_msgq, sizeof(NavCommand), MESSAGES_PER_QUEUE, alignof(NavCommand));
K_MSGQ_DEFINE(step_cmd_msgq, sizeof(StepCommand), MESSAGES_PER_QUEUE, alignof(StepCommand));


/* THREAD DEFINITION AND MANAGEMENT */

#define STACK_SIZE      1024*8

#define COMMS_PRIORITY  2
#define NAV_PRIORITY    1
#define STATE_PRIORITY  0

K_THREAD_STACK_DEFINE(comms_stack, STACK_SIZE);
K_THREAD_STACK_DEFINE(nav_stack, STACK_SIZE);
K_THREAD_STACK_DEFINE(state_stack, STACK_SIZE);

static struct k_thread comms_thread_data;
static struct k_thread nav_thread_data;
static struct k_thread state_thread_data;

    
/* HARDWARE INITIALIZATION */

static void hardware_init_work_handler(struct k_work *work) {
    printk("Starting hardware initialization...\n");
    
    // TODO: init hardware peripherals as they are added
    int ret = 0;
    ret = stepper_init();
    
    if (ret < 0) {
        printk("ERROR: Stepper initialization failed: %d\n", ret);
        post_state_event(Event::InitError);
    }

    printk("Hardware initialization completed successfully\n");
    
    // Post success event back to state machine
    post_state_event(Event::InitSuccess);
}

// Hardware initialization work item
K_WORK_DEFINE(hardware_init_work, hardware_init_work_handler);

/* MAIN FUNCTION */

int main(void) {
    
    k_thread_create(&comms_thread_data, comms_stack, STACK_SIZE,
                    comms_thread, &gcode_cmd_msgq, NULL, NULL,
                    COMMS_PRIORITY, 0, K_NO_WAIT);

    k_thread_create(&nav_thread_data, nav_stack, STACK_SIZE,
                    nav_thread, &gcode_cmd_msgq, &nav_cmd_msgq, &step_cmd_msgq,
                    NAV_PRIORITY, 0, K_NO_WAIT);

    k_thread_create(&state_thread_data, state_stack, STACK_SIZE,
                    state_thread, NULL, NULL, NULL,
                    STATE_PRIORITY, 0, K_NO_WAIT);

    
    post_state_event(Event::HardwareReset);
    
    return EXIT_SUCCESS;
}

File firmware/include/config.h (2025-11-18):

#pragma once

// #define DEBUG_BLE
// #define DEBUG_INSTRUCTION_PARSER
// #define DEBUG_NAV
#define DEBUG_MOTION
#define DEBUG_INTERPOLATE

#define WHEEL_DIAMETER          (47.30)
#define WHEELBASE               (127.5)

#define STEPPER_CTRL_FREQ       (5.0f)     // control frequency (Hz)

#define WHEEL_RADIUS            (WHEEL_DIAMETER / 2)
#define DOODLEBOT_RADIUS        (WHEELBASE / 2)   // distance from center of doodlebot to wheel
#define MAX_LINEAR_VELOCITY     (25.0f) // maximum linear velocity (mm/s)

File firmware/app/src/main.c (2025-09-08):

#include <zephyr/kernel.h>
#include <zephyr/device.h>
#include <stdlib.h>

#include "comms.h"
// #include "navigation.h"
#include "state.h"
// #include "ui.h"


#define STACK_SIZE      2048


#define COMMS_PRIORITY   1
// #define IMU_PRIORITY    2
// #define NAV_PRIORITY    3
#define STATE_PRIORITY  1

K_THREAD_STACK_DEFINE(comms_stack, STACK_SIZE);
// K_THREAD_STACK_DEFINE(imu_stack, STACK_SIZE);
// K_THREAD_STACK_DEFINE(nav_stack, STACK_SIZE);
K_THREAD_STACK_DEFINE(state_stack, STACK_SIZE);

static struct k_thread comms_thread_data;
// static struct k_thread imu_thread_data;
// static struct k_thread nav_thread_data;
static struct k_thread state_thread_data;

typedef bool (*init_func_t)(void);

int main(void) {

    // Initialize hardware

    k_thread_create(&comms_thread_data, comms_stack, STACK_SIZE,
                    comms_thread, NULL, NULL, NULL,
                    COMMS_PRIORITY, 0, K_NO_WAIT);

    // k_thread_create(&imu_thread_data, imu_stack, STACK_SIZE,
    //                 imu_thread, NULL, NULL, NULL,
    //                 IMU_PRIORITY, 0, K_NO_WAIT);

    // k_thread_create(&nav_thread_data, nav_stack, STACK_SIZE,
    //                 nav_thread, NULL, NULL, NULL,
    //                 NAV_PRIORITY, 0, K_NO_WAIT);

    k_thread_create(&state_thread_data, state_stack, STACK_SIZE,
                    state_thread, NULL, NULL, NULL,
                    STATE_PRIORITY, 0, K_NO_WAIT);

    return EXIT_SUCCESS;
}

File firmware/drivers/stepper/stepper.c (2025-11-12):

/**
 * Simple stepper motor driver for 1.8° motors with A4988 driver
 * Uses PWM hardware for precise step pulse generation (similar to servo driver)
 */

#include <zephyr/device.h>
#include <zephyr/drivers/gpio.h>
#include <zephyr/drivers/pwm.h>
#include <zephyr/devicetree.h>
#include <zephyr/logging/log.h>
#include <zephyr/kernel.h>
#include <math.h>
#include "stepper.h"

LOG_MODULE_REGISTER(stepper, CONFIG_LOG_DEFAULT_LEVEL);

/* Per-motor direction inversion */
#define INVERT_LEFT_DIRECTION true   // Left motor is physically backwards
#define INVERT_RIGHT_DIRECTION false // Right motor is correct

/* Stepper motor devicetree nodes */
#define STEPPER_LEFT_NODE  DT_NODELABEL(stepper_left)
#define STEPPER_RIGHT_NODE DT_NODELABEL(stepper_right)

#if !DT_NODE_EXISTS(STEPPER_LEFT_NODE)
#error "Stepper devicetree node 'stepper_left' not found"
#endif

/* GPIO pins for left stepper (primary) */
static const struct pwm_dt_spec step_pwm = PWM_DT_SPEC_GET(STEPPER_LEFT_NODE);
static const struct gpio_dt_spec dir_pin = GPIO_DT_SPEC_GET(STEPPER_LEFT_NODE, dir_gpios);
static const struct gpio_dt_spec en_pin = GPIO_DT_SPEC_GET(STEPPER_LEFT_NODE, en_gpios);

/* Helper functions for motor aliasing */
static int stepper_get_motor_pins(enum stepper_motor motor, 
                                 const struct pwm_dt_spec **pwm,
                                 const struct gpio_dt_spec **dir,
                                 const struct gpio_dt_spec **en)
{
    static const struct pwm_dt_spec right_step_pwm = PWM_DT_SPEC_GET(STEPPER_RIGHT_NODE);
    static const struct gpio_dt_spec right_dir_pin = GPIO_DT_SPEC_GET(STEPPER_RIGHT_NODE, dir_gpios);
    static const struct gpio_dt_spec right_en_pin = GPIO_DT_SPEC_GET(STEPPER_RIGHT_NODE, en_gpios);
    
    switch (motor) {
        case STEPPER_LEFT:
            *pwm = &step_pwm;
            *dir = &dir_pin;
            *en = &en_pin;
            return 0;
            
        case STEPPER_RIGHT:
#if DT_NODE_EXISTS(STEPPER_RIGHT_NODE) && DT_NODE_HAS_STATUS(STEPPER_RIGHT_NODE, okay)
            *pwm = &right_step_pwm;
            *dir = &right_dir_pin;
            *en = &right_en_pin;
            return 0;
#else
            LOG_ERR("Right stepper not available in devicetree");
            return -ENODEV;
#endif
            
        default:
            LOG_ERR("Invalid stepper motor: %d", motor);
            return -EINVAL;
    }
}

/* Constants for 1.8° stepper with 16x microstepping */
#define STEPS_PER_REV 200
#define MICROSTEPS 16
#define TOTAL_STEPS_PER_REV (STEPS_PER_REV * MICROSTEPS)  // 3200

/* Back to theoretical values */
#define DEG_TO_STEPS (TOTAL_STEPS_PER_REV / 360.0f)  // 8.89 steps/deg

/* State tracking - simplified for now, can be expanded per-motor later */
static bool initialized = false;
static bool left_enabled = false;
static bool right_enabled = false;

/* GPIO pulse counting for debugging */
static uint32_t gpio_pulse_count = 0;

/* PWM cycle tracking for precise debugging */
static uint32_t expected_pwm_cycles = 0;
static uint32_t movement_start_time = 0;
static uint32_t current_step_freq_hz = 0;
static uint32_t movement_step_freq_hz = 0;  /* Frequency during movement for calculations */
static bool step_counting_enabled = false;
static uint32_t current_movement_steps = 0;
static uint32_t total_step_count = 0;
static uint32_t expected_steps = 0;

int stepper_init(void)
{
    if (initialized) {
        return 0;
    }

    /* Check PWM device ready */
    if (!device_is_ready(step_pwm.dev)) {
        LOG_ERR("PWM device not ready");
        return -ENODEV;
    }

    /* Check GPIO ready for both steppers */
    if (!device_is_ready(dir_pin.port) || !device_is_ready(en_pin.port)) {
        LOG_ERR("Left stepper GPIO devices not ready");
        return -ENODEV;
    }

    /* Configure LEFT stepper GPIO pins */
    gpio_pin_configure_dt(&dir_pin, GPIO_OUTPUT_INACTIVE);
    gpio_pin_configure_dt(&en_pin, GPIO_OUTPUT_INACTIVE);

#if DT_NODE_EXISTS(STEPPER_RIGHT_NODE) && DT_NODE_HAS_STATUS(STEPPER_RIGHT_NODE, okay)
    /* Configure RIGHT stepper GPIO pins */
    static const struct gpio_dt_spec right_dir_pin = GPIO_DT_SPEC_GET(STEPPER_RIGHT_NODE, dir_gpios);
    static const struct gpio_dt_spec right_en_pin = GPIO_DT_SPEC_GET(STEPPER_RIGHT_NODE, en_gpios);
    
    if (!device_is_ready(right_dir_pin.port) || !device_is_ready(right_en_pin.port)) {
        LOG_ERR("Right stepper GPIO devices not ready");
        return -ENODEV;
    }
    
    gpio_pin_configure_dt(&right_dir_pin, GPIO_OUTPUT_INACTIVE);
    gpio_pin_configure_dt(&right_en_pin, GPIO_OUTPUT_INACTIVE);
    LOG_INF("Right stepper GPIO pins configured");
#endif  

    initialized = true;
    LOG_INF("Stepper initialized: 1.8° motor, 16x microstepping, PWM-based");

    return 0;
}

int stepper_enable(enum stepper_motor motor)
{
    if (!initialized) {
        stepper_init();
    }
    
    const struct pwm_dt_spec *pwm;
    const struct gpio_dt_spec *dir;
    const struct gpio_dt_spec *en;
    
    if (motor == STEPPER_BOTH) {
        /* Enable both motors */
        stepper_enable(STEPPER_LEFT);
#if DT_NODE_EXISTS(STEPPER_RIGHT_NODE) && DT_NODE_HAS_STATUS(STEPPER_RIGHT_NODE, okay)
        stepper_enable(STEPPER_RIGHT);
#endif
        return 0;
    }
    
    int ret = stepper_get_motor_pins(motor, &pwm, &dir, &en);
    if (ret < 0) {
        return ret;
    }

    gpio_pin_set_dt(en, 1);  // HIGH = enabled (this A4988 board)
    
    if (motor == STEPPER_LEFT) {
        left_enabled = true;
    } else if (motor == STEPPER_RIGHT) {
        right_enabled = true;
    }

    return 0;
}

int stepper_disable(enum stepper_motor motor)
{
    const struct pwm_dt_spec *pwm;
    const struct gpio_dt_spec *dir;
    const struct gpio_dt_spec *en;
    
    if (motor == STEPPER_BOTH) {
        /* Disable both motors */
        stepper_disable(STEPPER_LEFT);
#if DT_NODE_EXISTS(STEPPER_RIGHT_NODE) && DT_NODE_HAS_STATUS(STEPPER_RIGHT_NODE, okay)
        stepper_disable(STEPPER_RIGHT);
#endif
        return 0;
    }
    
    int ret = stepper_get_motor_pins(motor, &pwm, &dir, &en);
    if (ret < 0) {
        return ret;
    }
    
    /* Stop PWM */
    pwm_set_dt(pwm, 0, 0);
    
    gpio_pin_set_dt(en, 0);  // LOW = disabled
    
    if (motor == STEPPER_LEFT) {
        left_enabled = false;
    } else if (motor == STEPPER_RIGHT) {
        right_enabled = false;
    }

    return 0;
}
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

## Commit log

2025-09-08 create comms and state threads
2025-09-13 move state thread to state_task
2025-09-13 Setup state-machine framework
2025-09-25 pathfinding skeleton + v0 model
    [doodle_bot.stl]
2025-10-01 First draft of servo driver - WORKING!
    [doodle-servo.yaml, pwm-servo.yaml]
2025-10-02 Added Servo Driver in tests/
2025-10-06 Incorporated already-created led_gpio driver with my application layer code!
2025-10-08 Drafted Stepper Motor Driver Revision #1
2025-10-09 Updated Driver README
2025-10-11 move cam code and bt framework
2025-10-11 Got Buzzer, LED, and servo motor work on ESP32. Was missing a LEDC configuration in devicetree.
    [servo.c, servo_control.cpp]
2025-10-12 fixed incorporating the servo with the servo driver
    [doodle_servo.yaml]
2025-10-12 Got Dual Servos to work in Zephyr!
2025-10-13 Add PCB Folder
2025-10-13 Added PCB schematic
2025-10-13 Created working test case for PWM Buzzer
    [pwm_buzzer.c, pwm_buzzer_driver_test.cpp]
2025-10-13 Stepper Motor test working!
2025-10-15 path fix for gcode
    [bt_link.py, cv_core.py]
2025-10-15 Incorporated Stepper Motor and Servo motor changes.
2025-10-15 Fixed servo and LED configuration
    [peripheral_demo.cpp, servo.c, simple_led.c]
2025-10-16 spec 3 test working
    [navigation_circle.csv]
2025-10-24 app: fix compilation errors
    [navigation.cpp]
2025-10-24 stepper wrapper building
2025-10-25 Incorporated dual stepper functionality. Will need to fix why it is moving forward when it should be moving backward.
    [peripheral_demo.cpp, stepper.c, stepper_control.cpp]
2025-10-28 Fully added and tested multi-stepper motor functionality!
2025-10-28 debugging motor navigation to motor control and high frequency ble transmission
2025-10-30 two steppers driving
2025-10-30 Added Stepper enable functionality
2025-11-01 updated kinematics and documentation
2025-11-04 fw: update overlays so nrf builds and old esp32 one removed
2025-11-04 fw: remove unnecessary files
    [navigation_circle.csv]
2025-11-12 Changed left stepper motor orientation
2025-11-13 Add Project Files
    [DoodleBot.kicad_pcb, DoodleBot.kicad_sch, Motor Driver, LED, Buzzer Connections.kicad_sch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]
2025-11-13 stepper active idle
2025-11-14 Connor's version
    [DoodleBot.kicad_sch, Motor Driver, LED, Buzzer Connections.kicad_sch, Power_System.kicad_sch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]
2025-11-17 Jain's PCB! (The project is in its own folder)
    [DoodleBot-B_Cu.gbl, DoodleBot-B_Mask.gbs, DoodleBot-B_Paste.gbp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]
2025-11-17 Connor's Revisions #4!
    [DoodleBot-B_Cu.gbl, DoodleBot-B_Mask.gbs, DoodleBot-B_Paste.gbp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]
2025-11-17 Reorganized project structure
    [DoodleBot.kicad_pcb, DoodleBot.kicad_sch, external.kicad_sch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]
2025-11-17 Added wider 12V traces from 0.39mm to 0.45mm
    [DoodleBot.kicad_pcb]
